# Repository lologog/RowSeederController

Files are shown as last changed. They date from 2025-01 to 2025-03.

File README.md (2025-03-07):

# DC Motor Controller for Row Seeder

## Project Description
This project focuses on the design and development of a modular DC motor controller system for a row seeder.
The system ensures precise control over seed dispensing and supports communication with external devices via CAN protocol.

The project consists of a main controller board an an extension board connected via 2.54mm pin sockets:
- **Main Controller Board**: Handles motor control, sensor readings and CAN communication protocol.
- **Extension Board**: Adds high-current switches and extra digital inputs for expanded functionality.

This modular approach allows future modifications for broader compatibility and functionality.

---

## Features
### Main Controller Board:
- **Microcontroller**: STM32L476RGT6 (low power, high-performance Cortex-M4).
- **DC Motor Control**: H-bridge driver with speed and direction regulation using PWM.
- **CAN Communication**: Communication interface enabled by an SN65HVD230 transceiver, operating with a default baud rate of 500 kbits/s.
- **Sensor Inputs**:
  - Analog inputs (12V) for angle sensors.
  - Encoder inputs (5V and 12V) for speed control.

### Extension Board:
- **Digital Input Expansion**: Additional pins for external sensors or signals.
- **High-current Switches**: Reliable control of external loads through robust switches.
- **Modular Connectivity**: Connects seamlessly to the main board via pin sockets.

---

## PCB Renderings
- **Main Controller Board**:
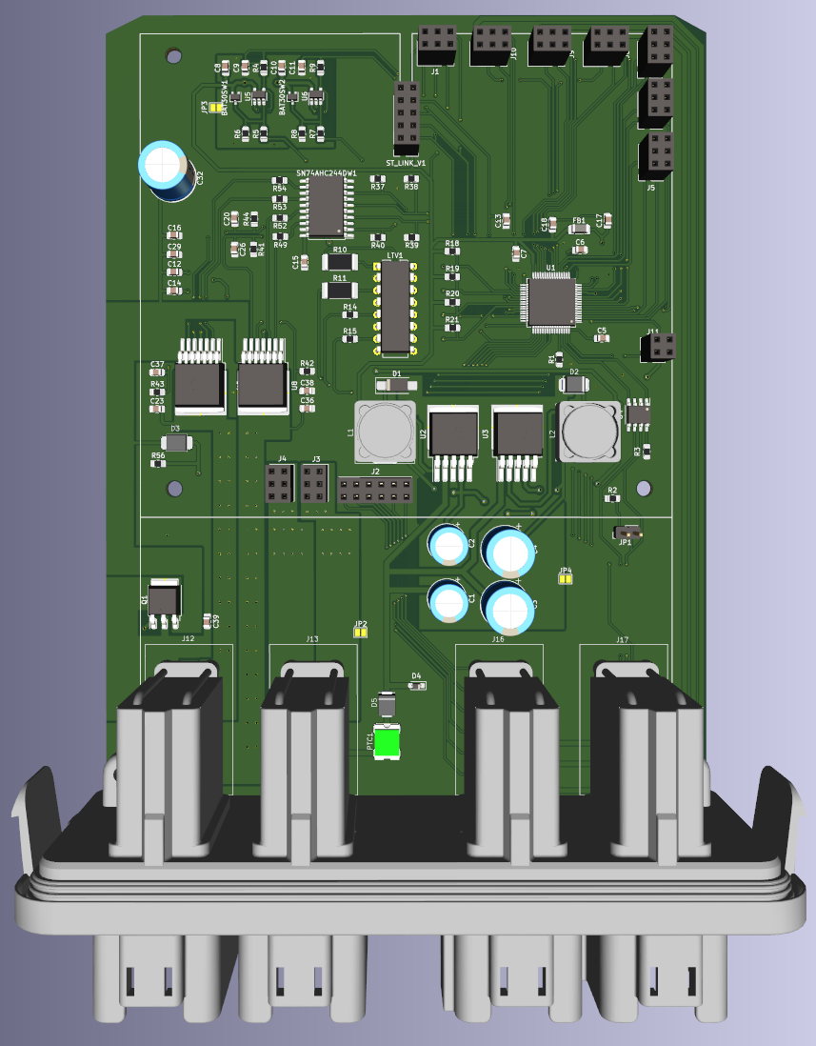
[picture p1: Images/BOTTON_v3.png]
  

- **Extension Board**:
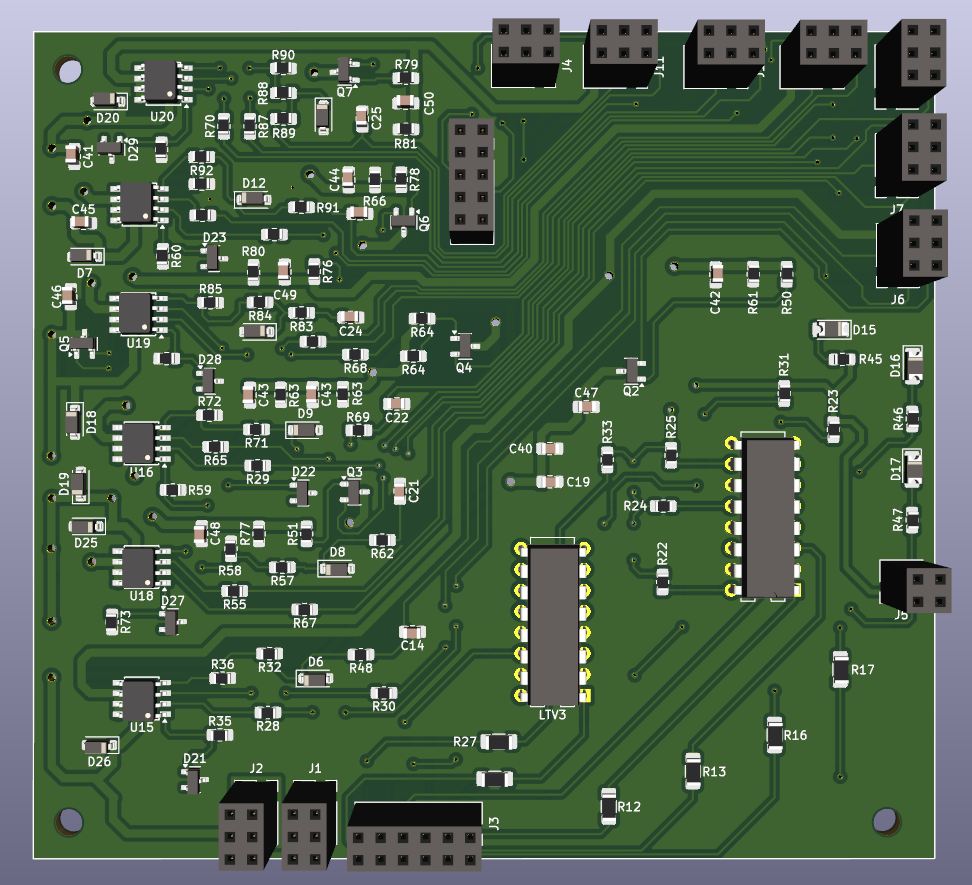
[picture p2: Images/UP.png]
  
  
  *Extension PCB made by my friend :)*

---

## **Real-World Implementation**
Below are images of the actual hardware implementation:

- **Fully assembled main controller**:
    

- **Main controller connected with extension board**:
    

- **Whole controller packed in a cover with 4 connectors**:
    

---

## Results
- **PWM Motor Control**: Verified precise speed and direction control for the DC motor.
- **Sensor Readings**: Successfully processed analog inputs and encoders.
- **PID Algorithm**: Achieved stable motor speed with minimal overshoot and fast response.
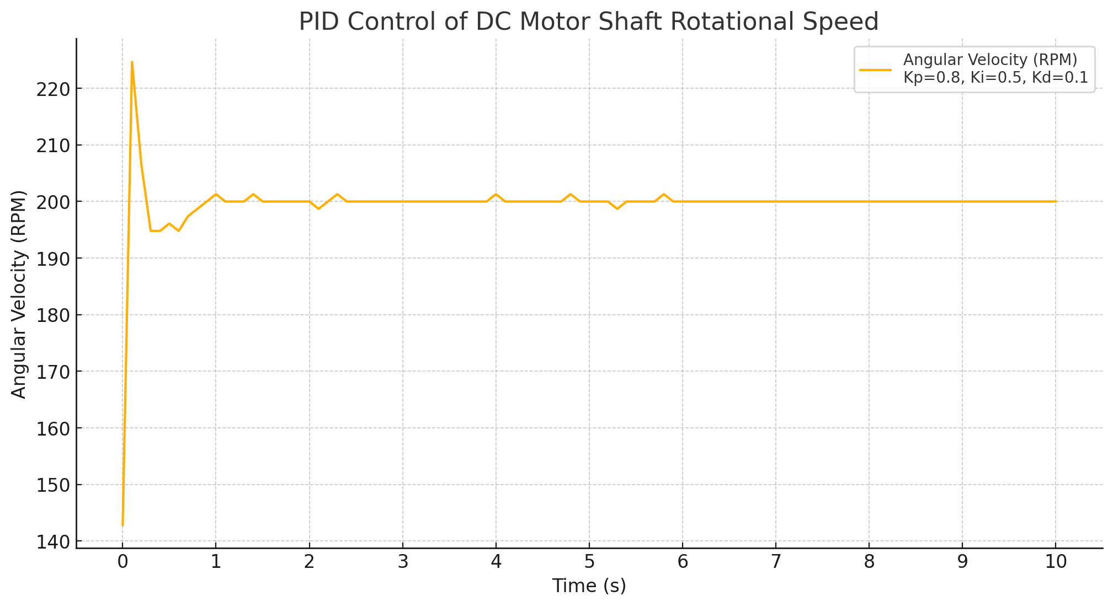
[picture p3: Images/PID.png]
  
  *Example motor angular velocity step response (fs = 10Hz)*
- **CAN Communication**: Reliable message transmission with external systems.
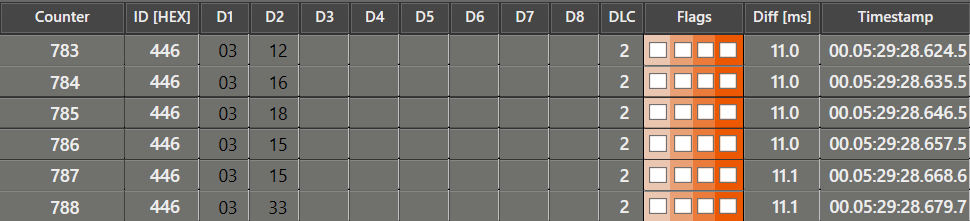
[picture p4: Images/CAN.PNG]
  
  *Sending analog reading of distance sensor via CAN bus*
  
---

## CAN Identifiers Documentation

The following table includes example CAN IDs and their corresponding actions. These IDs are meant as examples and should be adjusted to fit the needs of the target hardware and system.

| ID | Function | Parameters | Message Type | Notes |
|---|---|---|---|---|
| 0x01 | Ping | None | Response | Sends a "ping" response |
| 0x02 | Turn LED ON | None | Request | Turns on the LED |
| 0x03 | Turn LED OFF | None | Request | Turns off the LED |
| 0x04 | Toggle LED state | None | Request | Toggles the LED state |
| 0x05 | Read distance sensor 1  | ADC channel | Request | Reads analog measurement from channel 6 |
| 0x06 | Read distance sensor 2  | ADC channel | Request | Reads analog measurement from channel 7 |
| 0x07 | Turn on/off switch 1 | 1 (ON), other (OFF) | Request | Controls power switch 1 |
| 0x08 | Turn on/off switch 2 | 1 (ON), other (OFF) | Request | Controls power switch 2 |
| 0x09 | Turn on/off switch 3 | 1 (ON), other (OFF) | Request | Controls power switch 3 |
| 0x10 | Turn on/off switch 4 | 1 (ON), other (OFF) | Request | Controls power switch 4 |
| 0x11 | Turn on/off switch 5 | 1 (ON), other (OFF) | Request | Controls power switch 5 |
| 0x12 | Turn on/off switch 6 | 1 (ON), other (OFF) | Request | Controls power switch 6 |
| 0x13 | Motor PID control | RPM, direction | Request | PID control for motor speed |
| 0x14 | Stop motor | None | Request | Stops the motor |
| 0x15 | Motor percent control | Percent, direction | Request | Controls motor using percentage duty cycle|

---

## Potential Improvements
- Support for a broader range of motors and sensors.
- Add more communication protocols and better diagnostic.
- Motor measurement for better motor control.
- Enhanced firmware for fault detection and recovery.
- Improved PID regulation using extrapolation between samples and implementation of angular speed control through current measurement.

## Author
- **Name**: Krzysztof Tomicki
- **Contact**: tomicki.krzysztof.pv@gmail.com

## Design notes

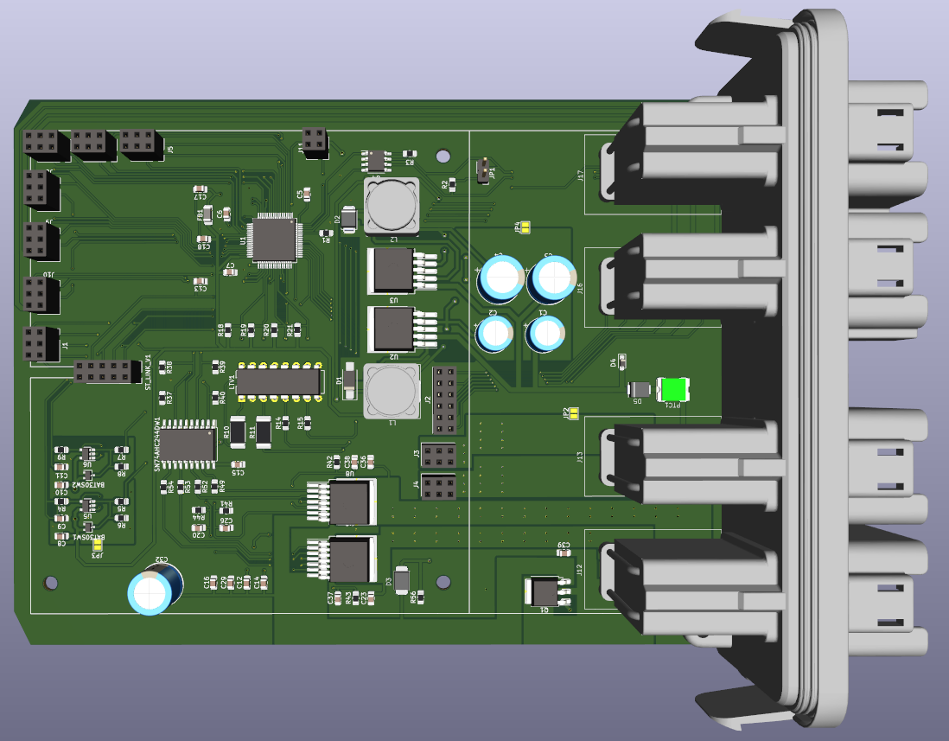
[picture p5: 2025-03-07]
Images/BOTTON_v2.png

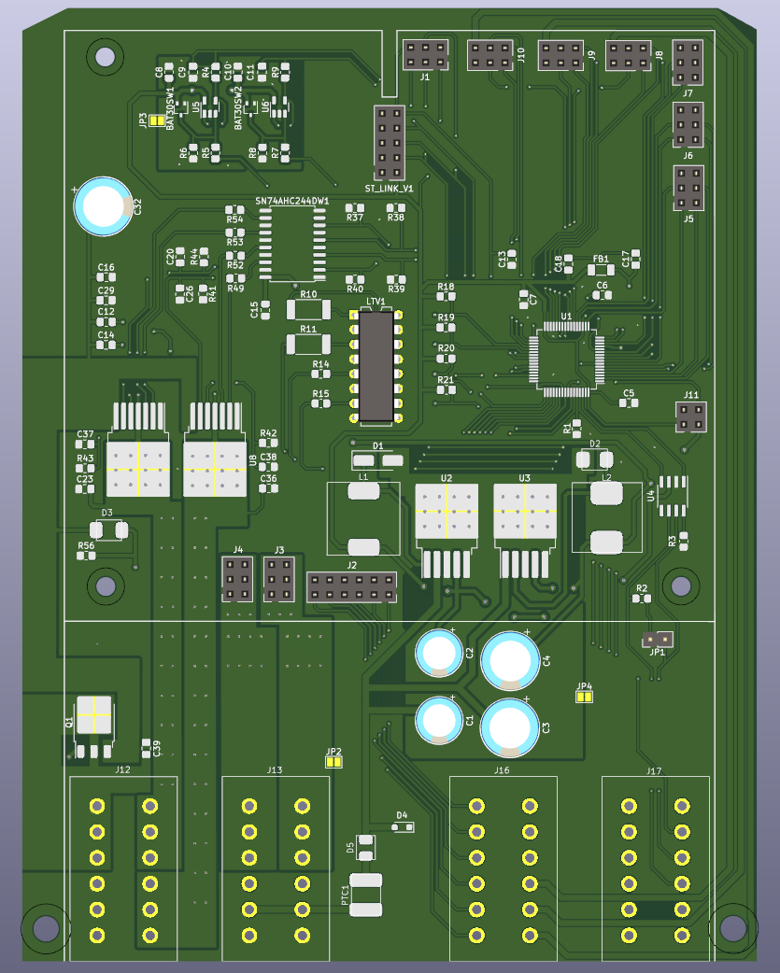
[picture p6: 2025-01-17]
Images/BOTTOM.png

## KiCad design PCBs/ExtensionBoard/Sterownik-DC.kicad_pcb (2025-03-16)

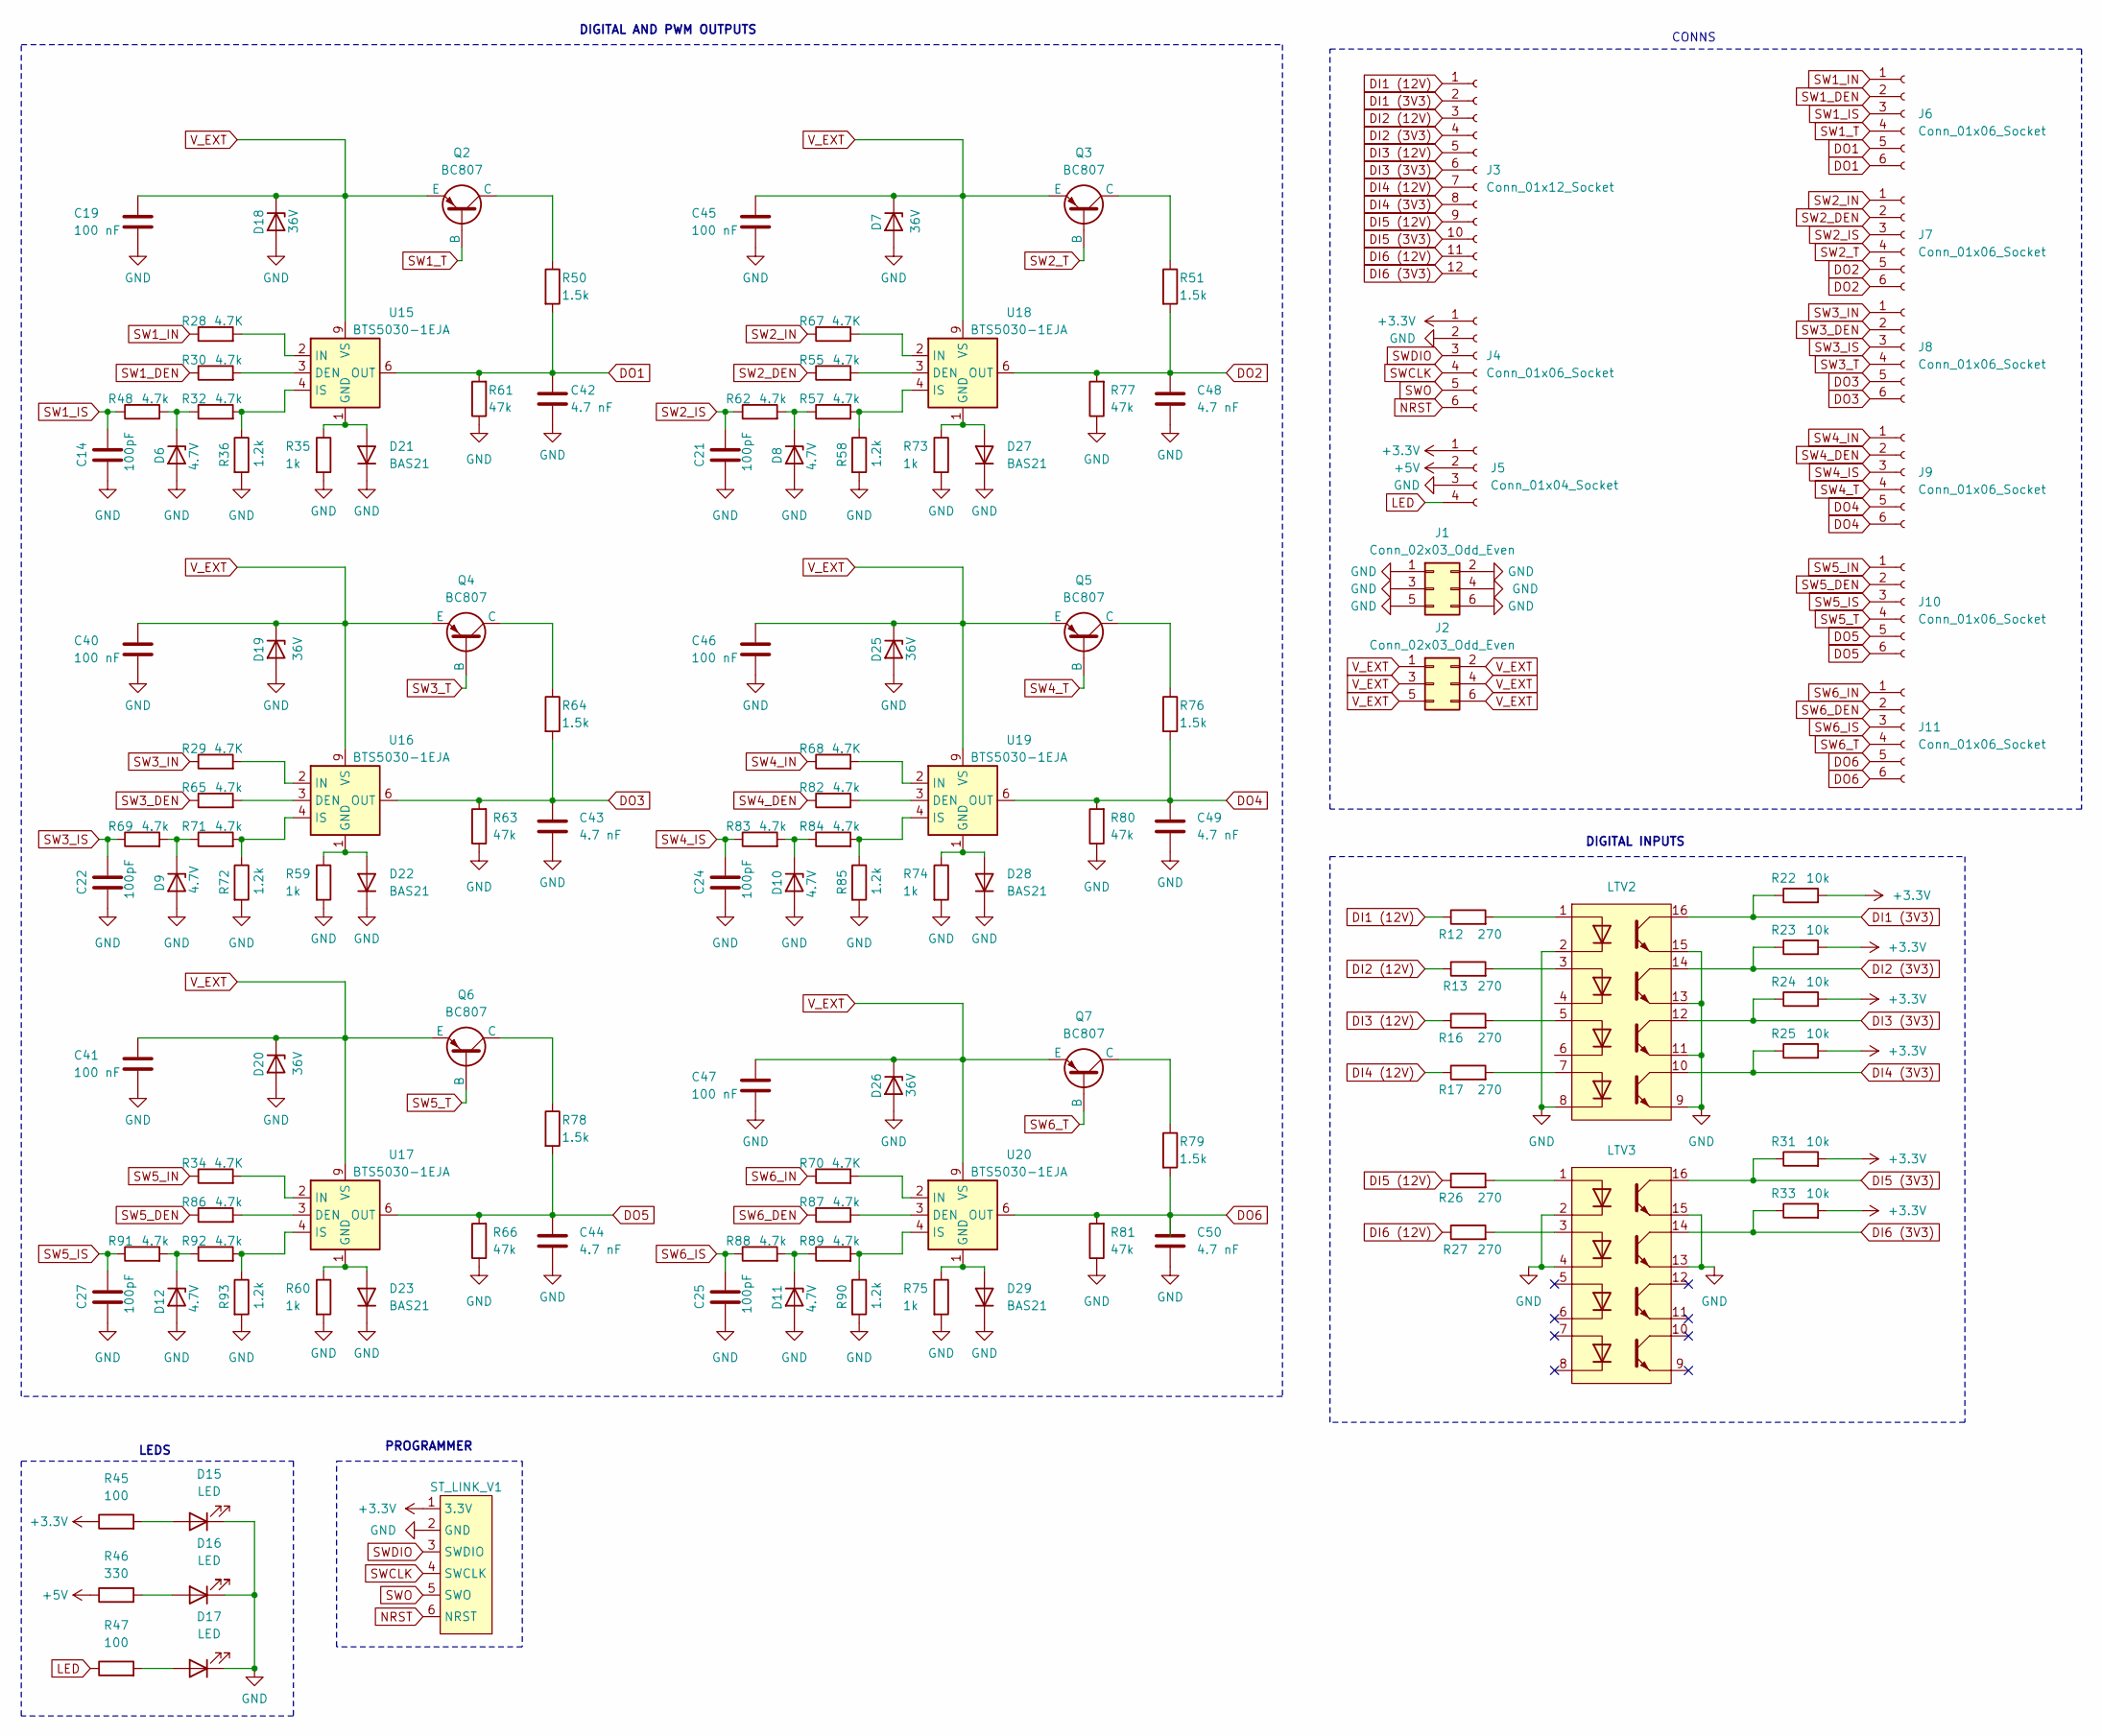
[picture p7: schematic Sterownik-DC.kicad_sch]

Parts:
C14, C21, C22, C24, C25, C27: 100pF; C_0805_2012Metric_Pad1.18x1.45mm_HandSolder
C19, C40, C41, C45, C46, C47: 100 nF; C_0805_2012Metric_Pad1.18x1.45mm_HandSolder
C42, C43, C44, C48, C49, C50: 4.7 nF; C_0805_2012Metric_Pad1.18x1.45mm_HandSolder
D6, D8, D9, D10, D11, D12: 4.7V; D_SOD-123
D7, D18, D19, D20, D25, D26: 36V; D_SOD-123
D15, D16, D17: LED; D_1206_3216Metric_Pad1.42x1.75mm_HandSolder
D21, D22, D23, D27, D28, D29: BAS21; SOT-23
J1, J2: Conn_02x03_Odd_Even; PinSocket_2x03_P2.54mm_Vertical
J3: Conn_01x12_Socket; PinSocket_2x06_P2.54mm_Vertical
J4, J6, J7, J8, J9, J10, J11: Conn_01x06_Socket; PinSocket_2x03_P2.54mm_Vertical
J5: Conn_01x04_Socket; PinSocket_2x02_P2.54mm_Vertical
LTV2, LTV3: DIP-16_W7.62mm
Q2, Q3, Q4, Q5, Q6, Q7: BC807; SOT-23-3
R12, R13, R16, R17, R26, R27: 270; R_1206_3216Metric_Pad1.30x1.75mm_HandSolder
R22, R23, R24, R25, R31, R33: 10k; R_0805_2012Metric_Pad1.20x1.40mm_HandSolder
R28, R29, R34, R67, R68, R70: 4.7K; R_0805_2012Metric_Pad1.20x1.40mm_HandSolder
R30, R32, R48, R55, R57, R62, R65, R69, R71, R82, R83, R84, R86, R87, R88, R89, R91, R92: 4.7k; R_0805_2012Metric_Pad1.20x1.40mm_HandSolder
R35, R59, R60, R73, R74, R75: 1k; R_0805_2012Metric_Pad1.20x1.40mm_HandSolder
R36, R58, R72, R85, R90, R93: 1.2k; R_0805_2012Metric_Pad1.20x1.40mm_HandSolder
R45, R47: 100; R_0805_2012Metric_Pad1.20x1.40mm_HandSolder
R46: 330; R_0805_2012Metric_Pad1.20x1.40mm_HandSolder
R50, R51, R64, R76, R78, R79: 1.5k; R_0805_2012Metric_Pad1.20x1.40mm_HandSolder
R61, R63, R66, R77, R80, R81: 47k; R_0805_2012Metric_Pad1.20x1.40mm_HandSolder
ST_LINK_V1: PinSocket_2x05_P2.54mm_Vertical
U15, U16, U17, U18, U19, U20: BTS5030-1EJA; Infineon_PG-DSO-8-43

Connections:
+3.3V: J4.1, J5.1, R22.2, R23.2, R24.2, R25.2, R31.2, R33.2, R45.1, ST_LINK_V1.1 (3.3V)
+5V: J5.2, R46.1
DI1 (3V3): J3.2, LTV2.16, R22.1
DI1 (12V): J3.1, R12.1
DI2 (3V3): J3.4, LTV2.14, R23.1
DI2 (12V): J3.3, R13.1
DI3 (3V3): J3.6, LTV2.12, R24.1
DI3 (12V): J3.5, R16.1
DI4 (3V3): J3.8, LTV2.10, R25.1
DI4 (12V): J3.7, R17.1
DI5 (3V3): J3.10, LTV3.16, R31.1
DI5 (12V): J3.9, R26.1
DI6 (3V3): J3.12, LTV3.14, R33.1
DI6 (12V): J3.11, R27.1
DO1: C42.1, J6.5, J6.6, R50.2, R61.2, U15.6 (OUT), U15.7 (OUT), U15.8 (OUT)
DO2: C48.1, J7.5, J7.6, R51.2, R77.2, U18.6 (OUT), U18.7 (OUT), U18.8 (OUT)
DO3: C43.1, J8.5, J8.6, R63.2, R64.2, U16.6 (OUT), U16.7 (OUT), U16.8 (OUT); also elsewhere on the board
DO4: C49.1, J9.5, J9.6, R76.2, R80.2, U19.6 (OUT), U19.7 (OUT), U19.8 (OUT)
DO5: C44.1, J10.5, J10.6, R66.2, R78.2, U17.6 (OUT), U17.7 (OUT), U17.8 (OUT)
DO6: C50.1, J11.5, J11.6, R79.2, R81.2, U20.6 (OUT), U20.7 (OUT), U20.8 (OUT)
GND: C14.1, C19.2, C21.1, C22.1, C24.1, C25.1, C27.1, C40.2, C41.2, C42.2, C43.2, C44.2, C45.2, C46.2, C47.2, C48.2, C49.2, C50.2, D6.2 (A), D7.2 (A), D8.2 (A), D9.2 (A), D10.2 (A), D12.2 (A), D15.1 (K), D16.1 (K), D17.1 (K), D18.2 (A), D19.2 (A), D20.2 (A), D21.3 (K), D22.3 (K), D23.3 (K), D25.2 (A), D26.2 (A), D27.3 (K), D28.3 (K), D29.3 (K), J1.1, J1.2, J1.3, J1.4, J1.5, J1.6, J4.2, J5.3, LTV2.2, LTV2.8, LTV2.9, LTV2.11, LTV2.13, LTV2.15, LTV3.2, LTV3.4, LTV3.13, LTV3.15, R35.2, R36.2, R58.2, R59.2, R60.2, R61.1, R63.1, R66.1, R72.2, R73.2, R74.2, R75.2, R77.1, R80.1, R81.1, R85.2, R90.2, R93.2, ST_LINK_V1.2 (GND); also elsewhere on the board
LED: J5.4, R47.1
NRST: J4.6, ST_LINK_V1.6 (NRST)
unnamed: D6.1 (K), R32.1, R48.2
unnamed: D8.1 (K), R57.1, R62.2
unnamed: D9.1 (K), R69.2, R71.1
unnamed: D10.1 (K), R83.2, R84.1
unnamed 27: D11.1 (K), R88.2, R89.1; also elsewhere on the board
unnamed: D12.1 (K), R91.2, R92.1
unnamed: D15.2 (A), R45.2
unnamed: D16.2 (A), R46.2
unnamed: D17.2 (A), R47.2
unnamed: D21.1 (A), R35.1, U15.1 (GND)
unnamed: D22.1 (A), R59.1, U16.1 (GND)
unnamed: D23.1 (A), R60.1, U17.1 (GND)
unnamed: D27.1 (A), R73.1, U18.1 (GND)
unnamed: D28.1 (A), R74.1, U19.1 (GND)
unnamed: D29.1 (A), R75.1, U20.1 (GND)
unnamed: LTV2.1, R12.2
unnamed: LTV2.3, R13.2
unnamed: LTV2.5, R16.2
unnamed: LTV2.7, R17.2
unnamed: LTV3.1, R26.2
unnamed: LTV3.3, R27.2
unnamed: Q2.1 (C), R50.1
unnamed: Q3.1 (C), R51.1
unnamed 46: Q4.1 (C), R64.1; also elsewhere on the board
unnamed: Q5.1 (C), R76.1
unnamed: Q6.1 (C), R78.1
unnamed: Q7.1 (C), R79.1
unnamed: R30.2, U15.3 (DEN)
unnamed: R28.2, U15.2 (IN)
unnamed: R32.2, R36.1, U15.4 (IS)
unnamed: R65.2, U16.3 (DEN)
unnamed: R29.2, U16.2 (IN)
unnamed: R71.2, R72.1, U16.4 (IS)
unnamed: R86.2, U17.3 (DEN)
unnamed: R34.2, U17.2 (IN)
unnamed: R92.2, R93.1, U17.4 (IS)
unnamed: R55.2, U18.3 (DEN)
unnamed: R67.2, U18.2 (IN)
unnamed: R57.2, R58.1, U18.4 (IS)
unnamed: R82.2, U19.3 (DEN)
unnamed: R68.2, U19.2 (IN)
unnamed: R84.2, R85.1, U19.4 (IS)
unnamed: R87.2, U20.3 (DEN)
unnamed: R70.2, U20.2 (IN)
unnamed: R89.2, R90.1, U20.4 (IS)
SW1_DEN: J6.2, R30.1
SW1_IN: J6.1, R28.1
SW1_IS: C14.2, J6.3, R48.1
SW1_T: J6.4, Q2.2 (B)
SW2_DEN: J7.2, R55.1
SW2_IN: J7.1, R67.1
SW2_IS: C21.2, J7.3, R62.1
SW2_T: J7.4, Q3.2 (B)
SW3_DEN: J8.2, R65.1
SW3_IN: J8.1, R29.1
SW3_IS: C22.2, J8.3, R69.1
SW3_T: J8.4, Q4.2 (B)
SW4_DEN: J9.2, R82.1
SW4_IN: J9.1, R68.1
SW4_IS: C24.2, J9.3, R83.1
SW4_T: J9.4, Q5.2 (B)
SW5_DEN: J10.2, R86.1
SW5_IN: J10.1, R34.1
SW5_IS: C27.2, J10.3, R91.1
SW5_T: J10.4, Q6.2 (B)
SW6_DEN: J11.2, R87.1
SW6_IN: J11.1, R70.1
SW6_IS: C25.2, J11.3, R88.1
SW6_T: J11.4, Q7.2 (B)
SWCLK: J4.4, ST_LINK_V1.4 (SWCLK)
SWDIO: J4.3, ST_LINK_V1.3 (SWDIO)
SWO: J4.5, ST_LINK_V1.5 (SWO)
V_EXT: C19.1, C40.1, C41.1, C45.1, C46.1, C47.1, D7.1 (K), D18.1 (K), D19.1 (K), D20.1 (K), D25.1 (K), D26.1 (K), J2.1, J2.2, J2.3, J2.4, J2.5, J2.6, Q2.3 (E), Q3.3 (E), Q4.3 (E), Q5.3 (E), Q6.3 (E), Q7.3 (E), U15.9 (VS), U16.9 (VS), U17.9 (VS), U18.9 (VS), U19.9 (VS), U20.9 (VS)

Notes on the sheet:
CONNS
DIGITAL INPUTS
DIGITAL AND PWM OUTPUTS
LEDS
PROGRAMMER

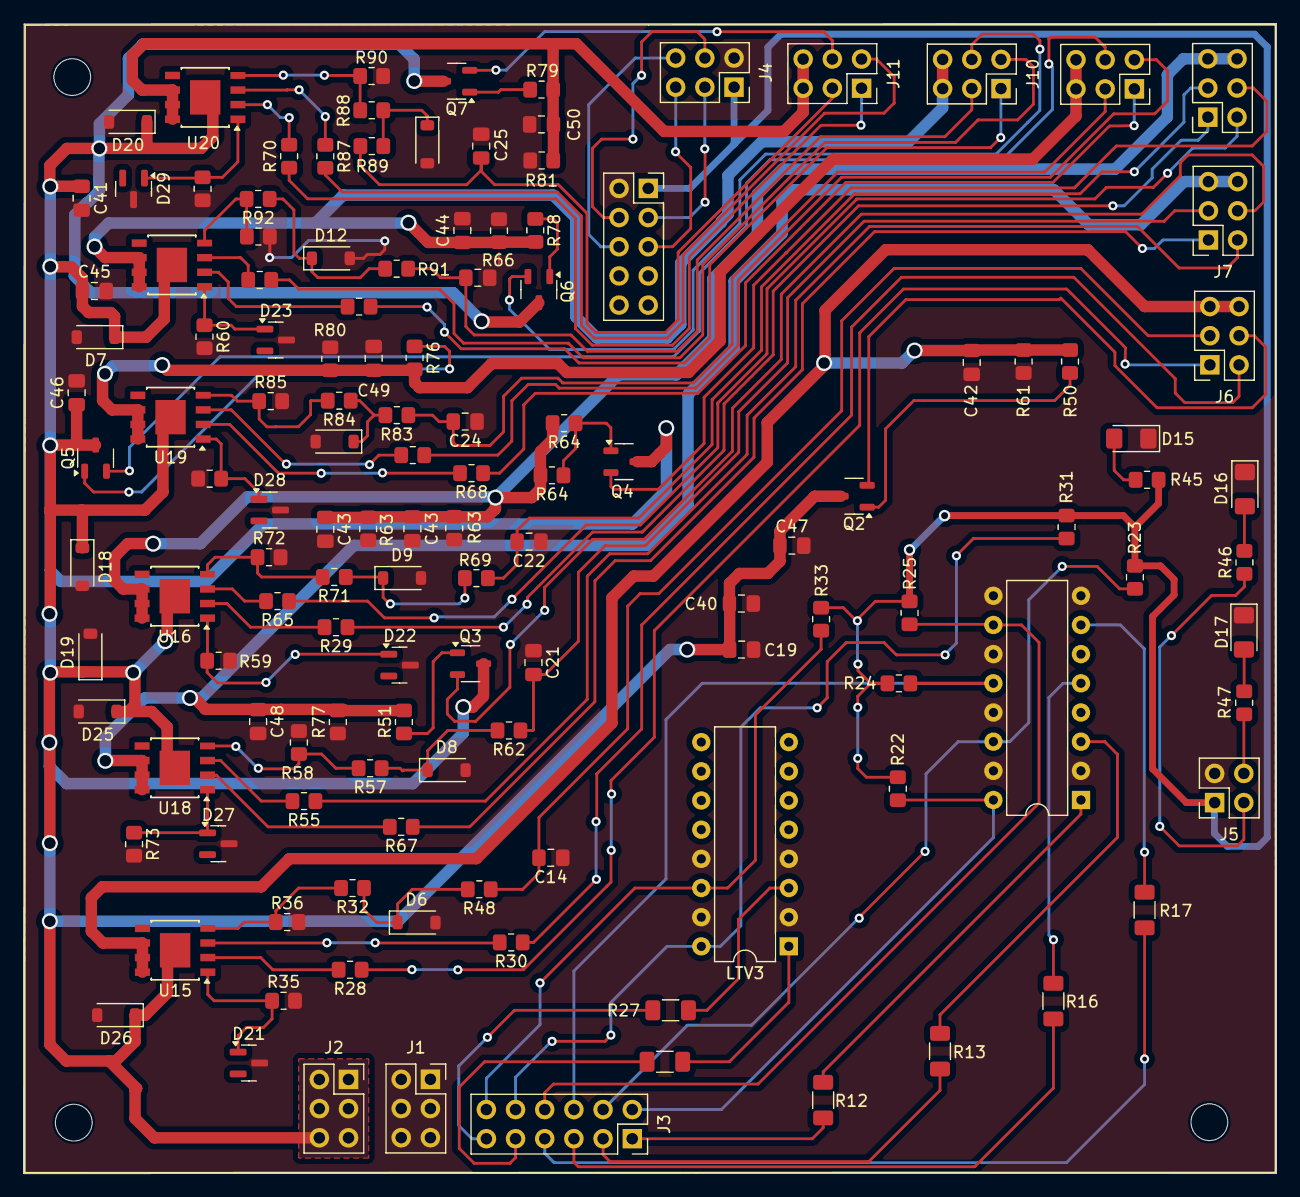
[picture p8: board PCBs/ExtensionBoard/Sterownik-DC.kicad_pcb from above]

Board: 2 copper layers, 109.1 x 100.1 mm, 131 parts (0 on the bottom side), 96 nets.

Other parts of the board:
C25#2: 4.7V; D_SOD-123
C43#2: 4.7 nF; C_0805_2012Metric_Pad1.18x1.45mm_HandSolder
R63#2: 47k; R_0805_2012Metric_Pad1.20x1.40mm_HandSolder
R64#2: 1.5k; R_0805_2012Metric_Pad1.20x1.40mm_HandSolder

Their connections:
DO3: C43#2.1, R63#2.2, R64#2.2; also elsewhere on the board
GND: C25#2.2 (A), C43#2.2, R63#2.1; also elsewhere on the board
unnamed 27: C25#2.1 (K); also elsewhere on the board
unnamed 46: R64#2.1; also elsewhere on the board

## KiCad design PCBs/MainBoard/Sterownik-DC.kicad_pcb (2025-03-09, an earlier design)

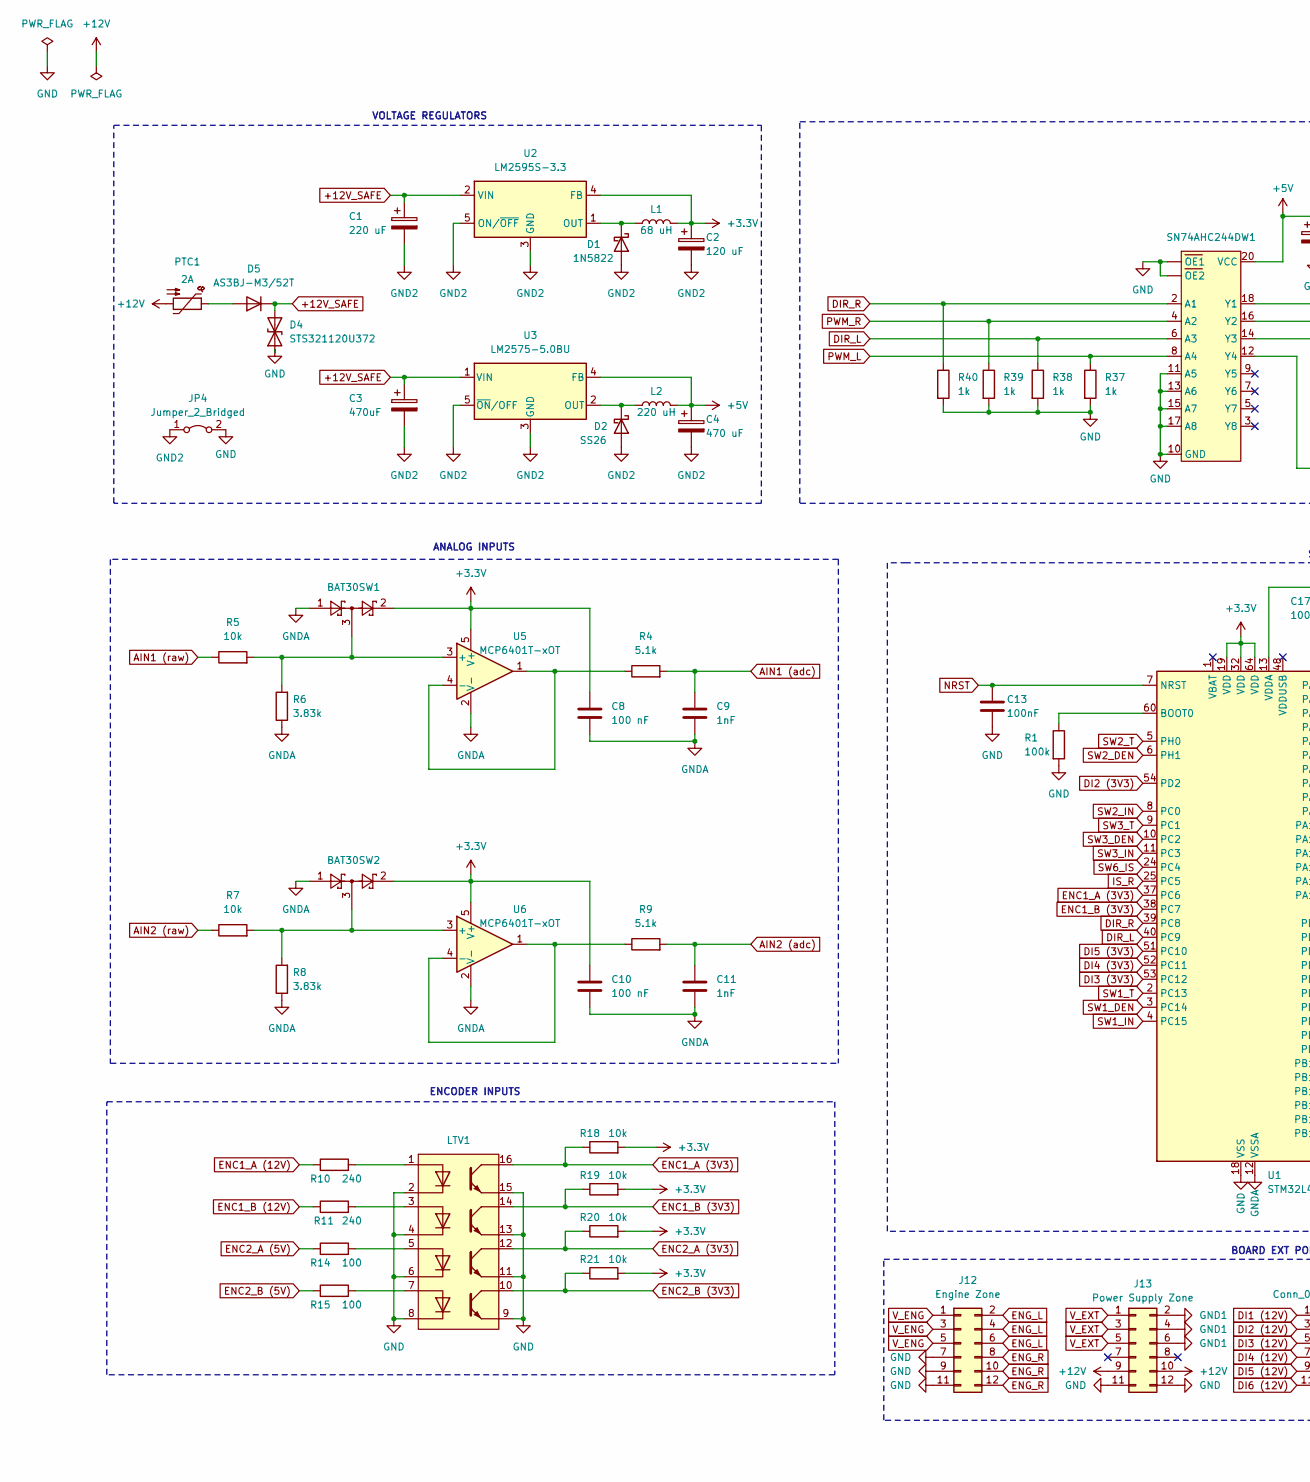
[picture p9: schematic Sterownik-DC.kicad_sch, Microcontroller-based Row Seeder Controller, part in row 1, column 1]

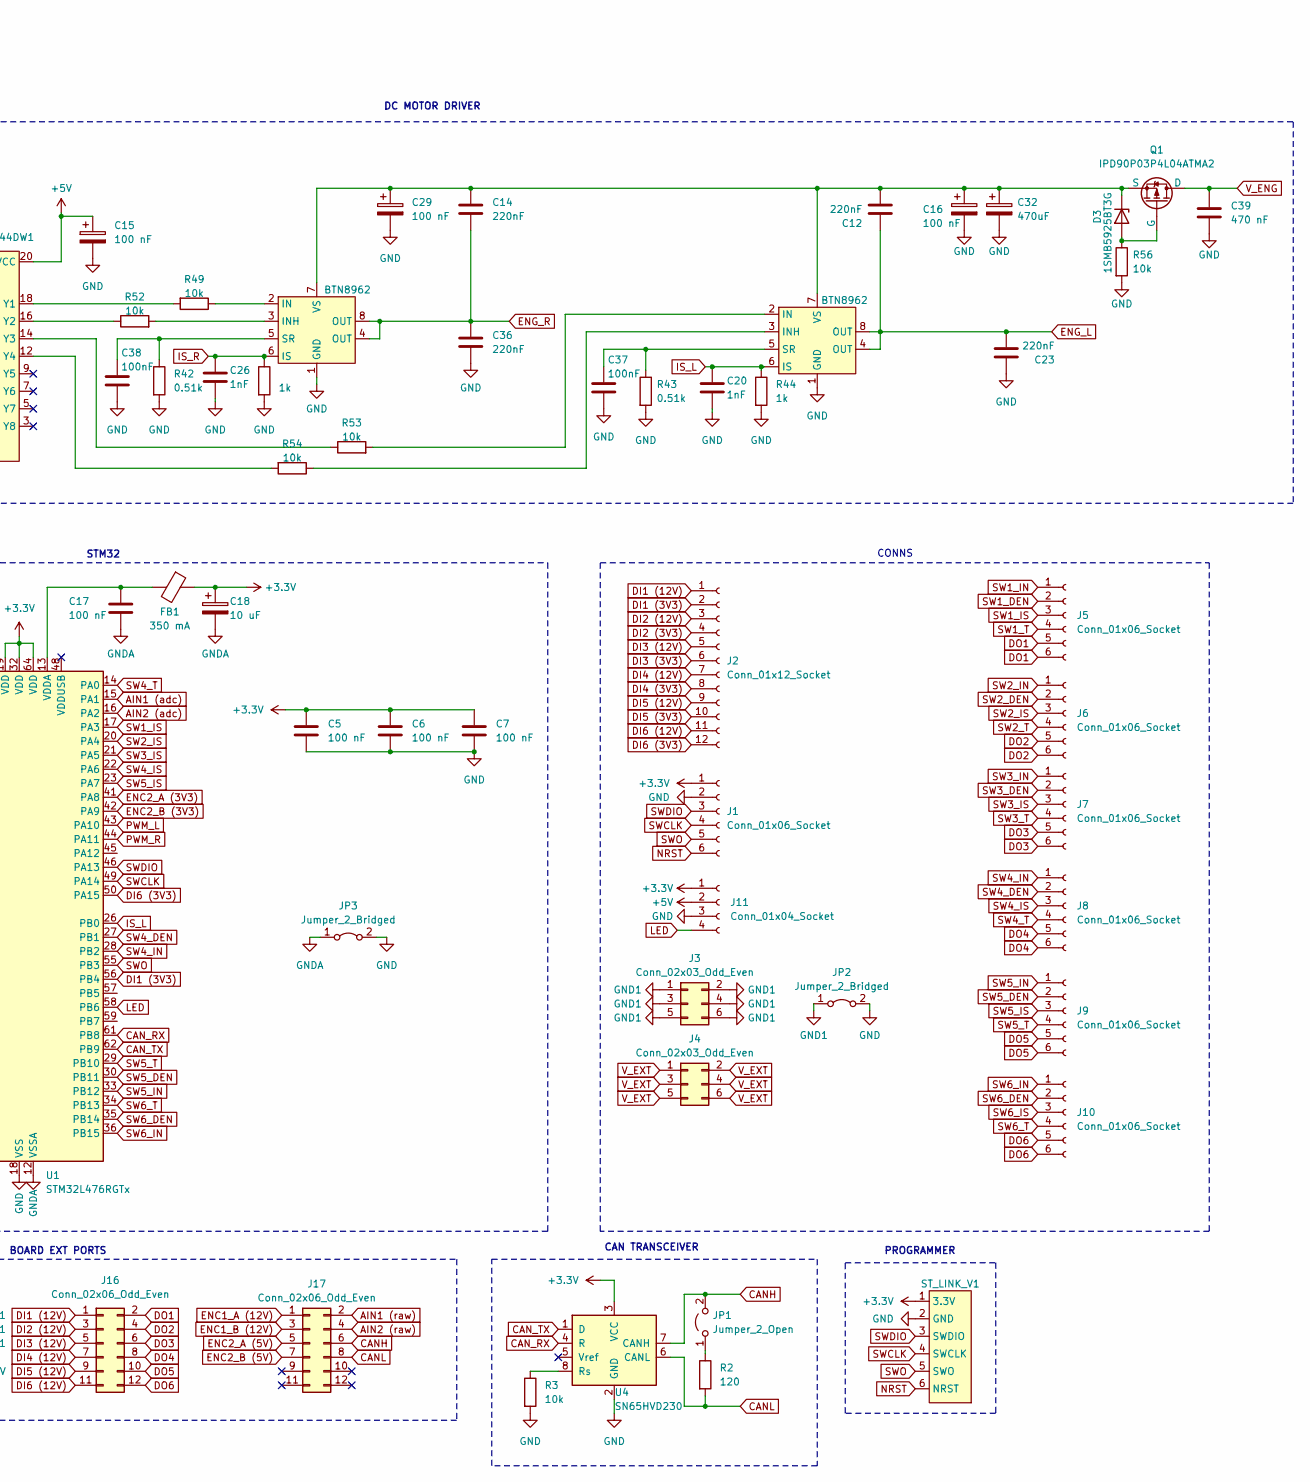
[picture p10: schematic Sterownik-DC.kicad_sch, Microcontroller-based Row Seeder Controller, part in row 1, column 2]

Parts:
BAT30SW1, BAT30SW2: SOT-323_SC-70
C1: 220 uF; CP_Radial_D8.0mm_P3.50mm
C2: 120 uF; CP_Radial_D8.0mm_P3.50mm
C3, C32: 470uF; CP_Radial_D10.0mm_P5.00mm
C4: 470 uF; CP_Radial_D10.0mm_P5.00mm
C5, C6, C7, C8, C10, C15, C16, C17, C29: 100 nF; C_0805_2012Metric_Pad1.18x1.45mm_HandSolder
C9, C11, C20, C26: 1nF; C_0805_2012Metric_Pad1.18x1.45mm_HandSolder
C12, C14, C23, C36: 220nF; C_0805_2012Metric_Pad1.18x1.45mm_HandSolder
C13, C37, C38: 100nF; C_0805_2012Metric_Pad1.18x1.45mm_HandSolder
C18: 10 uF; C_0805_2012Metric_Pad1.18x1.45mm_HandSolder
C39: 470 nF; C_0805_2012Metric_Pad1.18x1.45mm_HandSolder
D1: 1N5822; D_SMA_Handsoldering
D2: SS26; Zener_diode_DO-214AA
D3: 1SMB5925BT3G; 1SMB5913BT3
D4: STS321120U372; D_SOD-323_HandSoldering
D5: AS3BJ-M3/52T; AS3BJ-M3-52T
FB1: 350 mA; L_1206_3216Metric_Pad1.22x1.90mm_HandSolder
J1, J5, J6, J7, J8, J9, J10: Conn_01x06_Socket; PinSocket_2x03_P2.54mm_Vertical
J2: Conn_01x12_Socket; PinSocket_2x06_P2.54mm_Vertical
J3, J4: Conn_02x03_Odd_Even; PinSocket_2x03_P2.54mm_Vertical
J11: Conn_01x04_Socket; PinSocket_2x02_P2.54mm_Vertical
J12: Engine Zone; BIG_CONN
J13: Power Supply Zone; BIG_CONN
J16, J17: Conn_02x06_Odd_Even; BIG_CONN
JP1: Jumper_2_Open; PinHeader_1x02_P2.54mm_Vertical
JP2, JP3, JP4: Jumper_2_Bridged; SolderJumper-2_P1.3mm_Bridged2Bar_Pad1.0x1.5mm
L1: 68 uH; SRR1280
L2: 220 uH; MSS1246T
LTV1: DIP-16_W7.62mm
PTC1: 2A; 0ZCF Series
Q1: IPD90P03P4L04ATMA2; TO-252-3_TabPin2
R1: 100k; R_0805_2012Metric_Pad1.20x1.40mm_HandSolder
R2: 120; R_0805_2012Metric_Pad1.20x1.40mm_HandSolder
R3, R5, R7, R18, R19, R20, R21, R49, R52, R53, R54, R56: 10k; R_0805_2012Metric_Pad1.20x1.40mm_HandSolder
R4, R9: 5.1k; R_0805_2012Metric_Pad1.20x1.40mm_HandSolder
R6, R8: 3.83k; R_0805_2012Metric_Pad1.20x1.40mm_HandSolder
R10, R11: 240; R_2512_6332Metric_Pad1.40x3.35mm_HandSolder
R14, R15: 100; R_0805_2012Metric_Pad1.20x1.40mm_HandSolder
R37, R38, R39, R40, R41, R44: 1k; R_0805_2012Metric_Pad1.20x1.40mm_HandSolder
R42, R43: 0.51k; R_0805_2012Metric_Pad1.20x1.40mm_HandSolder
SN74AHC244DW1: SOIC-20W_7.5x12.8mm_P1.27mm
ST_LINK_V1: PinSocket_2x05_P2.54mm_Vertical
U1: STM32L476RGTx; LQFP-64_10x10mm_P0.5mm
U2: LM2595S-3.3; TO-263-5_TabPin3
U3: LM2575-5.0BU; TO-263-5_TabPin3
U4: SN65HVD230; SOIC-8_3.9x4.9mm_P1.27mm
U5, U6: MCP6401T-xOT; SOT-23-5
U8, U9: BTN8962; TO-263-7_TabPin8

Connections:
+3.3V: BAT30SW1.2, BAT30SW2.2, C2.1, C5.1, C6.1, C7.1, C8.1, C10.1, C18.1, FB1.1, J1.1, J11.1, L1.2, R18.2, R19.2, R20.2, R21.2, ST_LINK_V1.1 (3.3V), U1.19 (VDD), U1.32 (VDD), U1.64 (VDD), U2.4 (FB), U4.3 (VCC), U5.5 (V+), U6.5 (V+)
+5V: C4.1, C15.1, J11.2, L2.2, SN74AHC244DW1.20 (VCC), U3.4 (FB)
+12V: J13.9, J13.10, PTC1.2
+12V_SAFE: C1.1, C3.1, D4.2 (A2), D5.1 (K), U2.2 (VIN), U3.1 (VIN)
AIN1 (adc): C9.1, R4.2, U1.15 (PA1)
AIN1 (raw): J17.2, R5.1
AIN2 (adc): C11.1, R9.2, U1.16 (PA2)
AIN2 (raw): J17.4, R7.1
CANH: J17.6, JP1.2 (B), U4.7 (CANH)
CANL: J17.8, R2.2, U4.6 (CANL)
CAN_RX: U1.61 (PB8), U4.4 (R)
CAN_TX: U1.62 (PB9), U4.1 (D)
DI1 (3V3): J2.2, U1.56 (PB4)
DI1 (12V): J2.1, J16.1
DI2 (3V3): J2.4, U1.54 (PD2)
DI2 (12V): J2.3, J16.3
DI3 (3V3): J2.6, U1.53 (PC12)
DI3 (12V): J2.5, J16.5
DI4 (3V3): J2.8, U1.52 (PC11)
DI4 (12V): J2.7, J16.7
DI5 (3V3): J2.10, U1.51 (PC10)
DI5 (12V): J2.9, J16.9
DI6 (3V3): J2.12, U1.50 (PA15)
DI6 (12V): J2.11, J16.11
DIR_L: R38.1, SN74AHC244DW1.6 (A3), U1.40 (PC9)
DIR_R: R40.1, SN74AHC244DW1.2 (A1), U1.39 (PC8)
DO1: J5.5, J5.6, J16.2
DO2: J6.5, J6.6, J16.4
DO3: J7.5, J7.6, J16.6
DO4: J8.5, J8.6, J16.8
DO5: J9.5, J9.6, J16.10
DO6: J10.5, J10.6, J16.12
ENC1_A (3V3): LTV1.16, R18.1, U1.37 (PC6)
ENC1_A (12V): J17.1, R10.1
ENC1_B (3V3): LTV1.14, R19.1, U1.38 (PC7)
ENC1_B (12V): J17.3, R11.1
ENC2_A (3V3): LTV1.12, R20.1, U1.41 (PA8)
ENC2_A (5V): J17.5, R14.1
ENC2_B (3V3): LTV1.10, R21.1, U1.42 (PA9)
ENC2_B (5V): J17.7, R15.1
ENG_L: C12.1, C23.2, J12.2, J12.4, J12.6, U9.4 (OUT), U9.8 (OUT)
ENG_R: C14.2, C36.1, J12.8, J12.10, J12.12, U8.4 (OUT), U8.8 (OUT)
GND: C5.2, C6.2, C7.2, C13.2, C15.2, C16.2, C20.2, C23.1, C26.2, C29.2, C32.2, C36.2, C37.2, C38.2, C39.2, D4.1 (A1), J1.2, J11.3, J12.7, J12.9, J12.11, J13.11, J13.12, JP2.2 (B), JP3.2 (B), JP4.2 (B), LTV1.2, LTV1.4, LTV1.6, LTV1.8, LTV1.9, LTV1.11, LTV1.13, LTV1.15, R1.2, R3.2, R37.2, R38.2, R39.2, R40.2, R41.2, R42.2, R43.2, R44.2, R56.2, SN74AHC244DW1. (OE1), SN74AHC244DW1.1 (OE1), SN74AHC244DW1.10 (GND), SN74AHC244DW1.11 (A5), SN74AHC244DW1.13 (A6), SN74AHC244DW1.15 (A7), SN74AHC244DW1.17 (A8), SN74AHC244DW1.19 (OE2), ST_LINK_V1.2 (GND), U1.18 (VSS), U1.31 (VSS), U1.47 (VSS), U1.63 (VSS), U4.2 (GND), U8.1 (GND), U9.1 (GND)
GND1: J3.1, J3.2, J3.3, J3.4, J3.5, J3.6, J13.2, J13.4, J13.6, JP2.1 (A)
GND2: C1.2, C2.2, C3.2, C4.2, D1.2 (A), D2.2 (A), JP4.1 (A), U2.3 (GND), U2.5 (ON/~OFF), U3.3 (GND), U3.5 (~ON/OFF)
GNDA: BAT30SW1.1, BAT30SW2.1, C8.2, C9.2, C10.2, C11.2, C17.2, C18.2, JP3.1 (A), R6.1, R8.1, U1.12 (VSSA), U5.2 (V-), U6.2 (V-)
IS_L: C20.1, R44.1, U1.26 (PB0), U9.6 (IS)
IS_R: C26.1, R41.1, U1.25 (PC5), U8.6 (IS)
LED: J11.4, U1.58 (PB6)
NRST: C13.1, J1.6, ST_LINK_V1.6 (NRST), U1.7 (NRST)
unnamed: D1.1 (K), L1.1, U2.1 (OUT)
unnamed: D2.1 (K), L2.1, U3.2 (OUT)
unnamed: D3.2 (A), Q1.1 (G), R56.1
unnamed: C12.2, C14.1, C16.1, C29.1, C32.1, D3.1 (K), Q1.3 (S), U8.7 (VS), U9.7 (VS)
unnamed: D5.2 (A), PTC1.1
unnamed: JP1.1 (A), R2.1
unnamed: LTV1.1, R10.2
unnamed: LTV1.3, R11.2
unnamed: LTV1.5, R14.2
unnamed: LTV1.7, R15.2
unnamed: R49.2, SN74AHC244DW1.18 (Y1)
unnamed: R52.1, SN74AHC244DW1.16 (Y2)
unnamed: R53.1, SN74AHC244DW1.14 (Y3)
unnamed: R54.2, SN74AHC244DW1.12 (Y4)
unnamed: R1.1, U1.60 (BOOT0)
unnamed: C17.1, FB1.2, U1.13 (VDDA)
unnamed: R3.1, U4.8 (Rs)
unnamed: BAT30SW1.3, R5.2, R6.2, U5.3 (+)
unnamed: R4.1, U5.1, U5.4 (-)
unnamed: BAT30SW2.3, R7.2, R8.2, U6.3 (+)
unnamed: R9.1, U6.1, U6.4 (-)
unnamed: R49.1, U8.2 (IN)
unnamed: R52.2, U8.3 (INH)
unnamed: C38.1, R42.1, U8.5 (SR)
unnamed: R53.2, U9.2 (IN)
unnamed: R54.1, U9.3 (INH)
unnamed: C37.1, R43.1, U9.5 (SR)
PWM_L: R37.1, SN74AHC244DW1.8 (A4), U1.43 (PA10)
PWM_R: R39.1, SN74AHC244DW1.4 (A2), U1.44 (PA11)
SW1_DEN: J5.2, U1.3 (PC14)
SW1_IN: J5.1, U1.4 (PC15)
SW1_IS: J5.3, U1.17 (PA3)
SW1_T: J5.4, U1.2 (PC13)
SW2_DEN: J6.2, U1.6 (PH1)
SW2_IN: J6.1, U1.8 (PC0)
SW2_IS: J6.3, U1.20 (PA4)
SW2_T: J6.4, U1.5 (PH0)
SW3_DEN: J7.2, U1.10 (PC2)
SW3_IN: J7.1, U1.11 (PC3)
SW3_IS: J7.3, U1.21 (PA5)
SW3_T: J7.4, U1.9 (PC1)
SW4_DEN: J8.2, U1.27 (PB1)
SW4_IN: J8.1, U1.28 (PB2)
SW4_IS: J8.3, U1.22 (PA6)
SW4_T: J8.4, U1.14 (PA0)
SW5_DEN: J9.2, U1.30 (PB11)
SW5_IN: J9.1, U1.33 (PB12)
SW5_IS: J9.3, U1.23 (PA7)
SW5_T: J9.4, U1.29 (PB10)
SW6_DEN: J10.2, U1.35 (PB14)
SW6_IN: J10.1, U1.36 (PB15)
SW6_IS: J10.3, U1.24 (PC4)
SW6_T: J10.4, U1.34 (PB13)
SWCLK: J1.4, ST_LINK_V1.4 (SWCLK), U1.49 (PA14)
SWDIO: J1.3, ST_LINK_V1.3 (SWDIO), U1.46 (PA13)
SWO: J1.5, ST_LINK_V1.5 (SWO), U1.55 (PB3)
V_ENG: C39.1, J12.1, J12.3, J12.5, Q1.2 (D)
V_EXT: J4.1, J4.2, J4.3, J4.4, J4.5, J4.6, J13.1, J13.3, J13.5

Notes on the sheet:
DC MOTOR DRIVER
CONNS
PROGRAMMER
CAN TRANSCEIVER
ANALOG INPUTS
BOARD EXT PORTS
ENCODER INPUTS
STM32
VOLTAGE REGULATORS

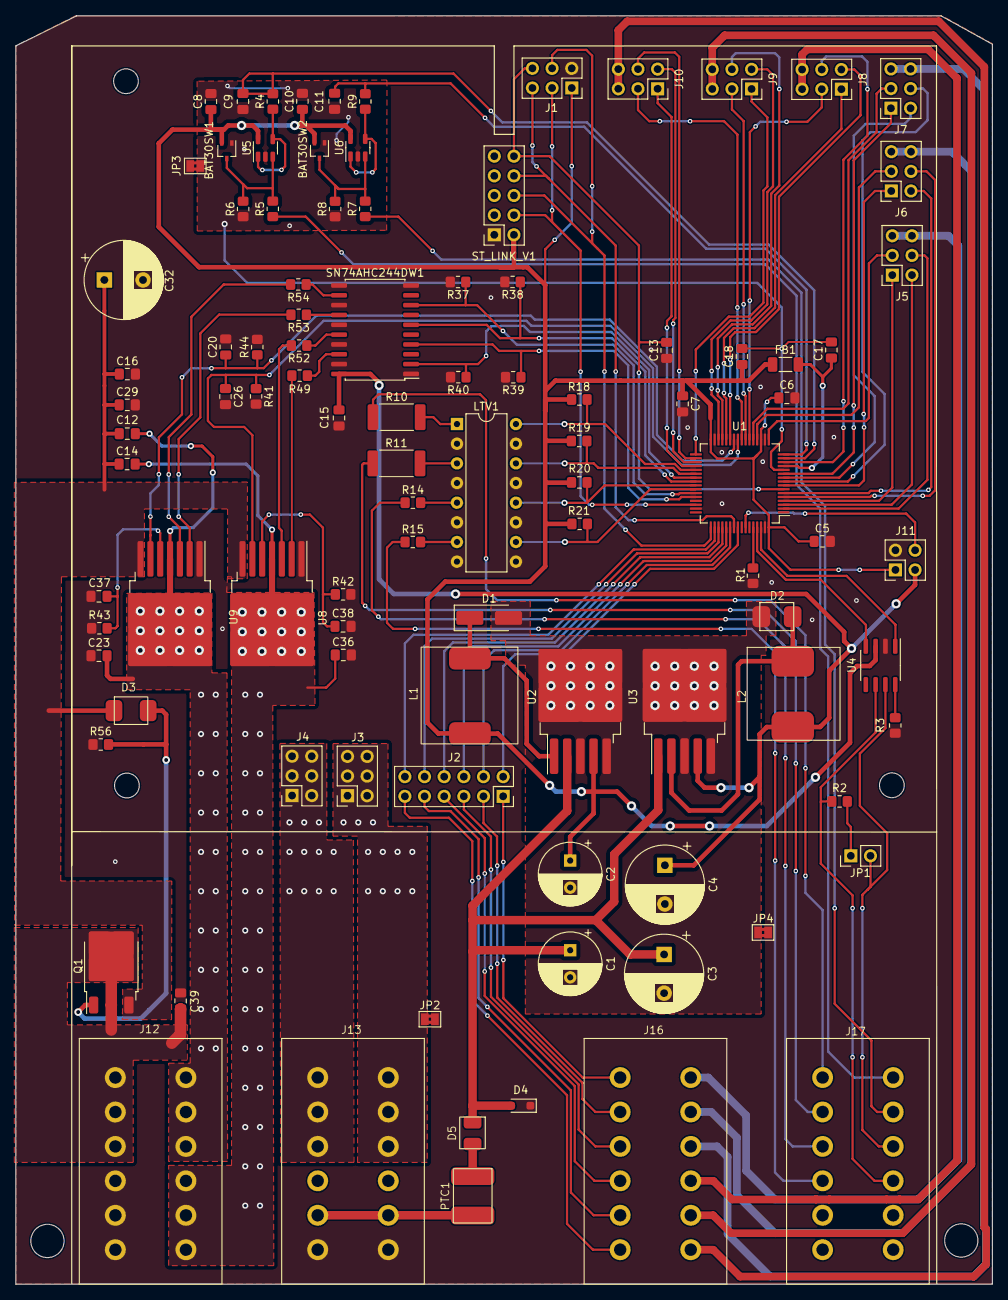
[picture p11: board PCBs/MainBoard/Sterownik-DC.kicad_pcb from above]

Board: 2 copper layers, 126.2 x 163.9 mm, 99 parts (0 on the bottom side), 108 nets.

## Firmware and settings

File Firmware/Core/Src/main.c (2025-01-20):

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
/* Includes ------------------------------------------------------------------*/
#include "main.h"

/* USER CODE BEGIN Includes */
#include "motor.h"
#include "led.h"
#include "encoder.h"
#include "can.h"
#include  "can_logic.h"
/* USER CODE END Includes */

ADC_HandleTypeDef hadc1;

CAN_HandleTypeDef hcan1;

TIM_HandleTypeDef htim1;
TIM_HandleTypeDef htim2;
TIM_HandleTypeDef htim4;
TIM_HandleTypeDef htim8;

void SystemClock_Config(void);
static void MX_GPIO_Init(void);
static void MX_ADC1_Init(void);
static void MX_TIM1_Init(void);
static void MX_TIM4_Init(void);
static void MX_TIM8_Init(void);
static void MX_TIM2_Init(void);
static void MX_CAN1_Init(void);
/* USER CODE BEGIN 0 */
//interrupt if something went through CAN filters and is in FIFO0
void HAL_CAN_RxFifo0MsgPendingCallback(CAN_HandleTypeDef *hcan)
{
    CAN_RxHeaderTypeDef RxHeader;
    uint8_t rxData[8];

    if (HAL_CAN_GetRxMessage(hcan, CAN_RX_FIFO0, &RxHeader, rxData) == HAL_OK)
    {
    	//function with logic
        Process_CAN_Message(RxHeader.StdId, rxData, RxHeader.DLC);
    }
}

uint32_t adc_value[10];
// choosing channel and getting ADC value
uint32_t Read_ADC(ADC_HandleTypeDef *hadc, uint32_t AdcChannel)
{
	// configuration
	ADC_ChannelConfTypeDef sConfig = {0};
	sConfig.Channel = AdcChannel;
	sConfig.Rank = 1;
	sConfig.SamplingTime = ADC_SAMPLETIME_2CYCLE_5;
	if (HAL_ADC_ConfigChannel(hadc, &sConfig) != HAL_OK)
	{
		Error_Handler();
	}

	//read ADC value
	HAL_ADC_Start(hadc);
	if (HAL_ADC_PollForConversion(hadc, 10) == HAL_OK)
	{
		return HAL_ADC_GetValue(hadc);
	}
	else
	{
		Error_Handler();
		return 0;
	}
}

// Toggling state of IN pin of power switches
void PowerSwitchOnOffDiagnostic(uint8_t DeviceNumber, GPIO_PinState PinState)
{
    switch(DeviceNumber)
    {
        case 1:
            HAL_GPIO_WritePin(SW1_IN_GPIO_Port, SW1_IN_Pin, PinState);
            break;
        case 2:
            HAL_GPIO_WritePin(SW2_IN_GPIO_Port, SW2_IN_Pin, PinState);
            break;
        case 3:
            HAL_GPIO_WritePin(SW3_IN_GPIO_Port, SW3_IN_Pin, PinState);
            break;
        case 4:
            HAL_GPIO_WritePin(SW4_IN_GPIO_Port, SW4_IN_Pin, PinState);
            break;
        case 5:
            HAL_GPIO_WritePin(SW5_IN_GPIO_Port, SW5_IN_Pin, PinState);
            break;
        case 6:
            HAL_GPIO_WritePin(SW6_IN_GPIO_Port, SW6_IN_Pin, PinState);
            break;
        default:
            break;
    }
}

uint16_t RPM = 0;
MotorDirection_t direction = MOTOR_LEFT;
uint8_t duty = 0;
uint8_t motor_percent_flag = 0;
/* USER CODE END 0 */

/**
  * @brief  The application entry point.
  * @retval int
  */
int main(void)
{
  /* MCU Configuration--------------------------------------------------------*/

  /* Reset of all peripherals, Initializes the Flash interface and the Systick. */
  HAL_Init();

  /* Configure the system clock */
  SystemClock_Config();

  /* Initialize all configured peripherals */
  MX_GPIO_Init();
  MX_ADC1_Init();
  MX_TIM1_Init();
  MX_TIM4_Init();
  MX_TIM8_Init();
  MX_TIM2_Init();
  MX_CAN1_Init();
  /* USER CODE BEGIN 2 */
  Motor_Init();
  Encoder_Init(ENCODER_5V);
  Encoder_Init(ENCODER_12V);
  CAN_Init(&hcan1);
  CAN_ConfigFilters(&hcan1, 0x000, 0x000); //mask will check all bytes of ID if the mask value is set to 0x7FF
  HAL_TIM_Base_Start_IT(&htim2);
  HAL_ADC_Start(&hadc1);

  //turn off all diagnostic pins of power switches
  for (uint8_t i = 0; i < 6; i++)
  {
	 PowerSwitchOnOffDiagnostic(i, 0);
  }

  /* USER CODE END 2 */

  /* Infinite loop */
  /* USER CODE BEGIN WHILE */
  while (1)
  {
	  //percent motor control possible to enable by CAN
	  if (motor_percent_flag == 1)
	  {
		  Motor_Percent_Control(direction, duty);
	  }
    /* USER CODE END WHILE */

    /* USER CODE BEGIN 3 */
  }
  /* USER CODE END 3 */
}

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
/* USER CODE BEGIN 4 */

/* TIM2 interrupt handler for RPM measurement */
void HAL_TIM_PeriodElapsedCallback(TIM_HandleTypeDef *htim)
{
    if (htim->Instance == TIM2) // Check if the interrupt is from TIM2
    {
        uint32_t desired_RPM = RPM * 1000; // Desired RPM scaled by 1000
        uint32_t current_RPM = Encoder_GetScaledRPM(ENCODER_5V); // Scaled RPM

    	//We need to split 32 bit int into 4x8bit bytes to send via CAN bus
    	uint8_t byte1 = (current_RPM >> 24) & 0xFF; //MSB
    	uint8_t byte2 = (current_RPM >> 16) & 0xFF;
    	uint8_t byte3 = (current_RPM >> 8) & 0xFF;
    	uint8_t byte4 = current_RPM & 0xFF; //LSB

    	CAN_SendMessage(&hcan1, 0x200, (uint8_t[]){byte1, byte2, byte3, byte4}, 4);

    	Motor_PID_Control(direction, desired_RPM, current_RPM);
    }
}
/* USER CODE END 4 */
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


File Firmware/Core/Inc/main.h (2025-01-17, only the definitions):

#define SW1_T_Pin GPIO_PIN_13
#define SW1_T_GPIO_Port GPIOC
#define SW1_DEN_Pin GPIO_PIN_14
#define SW1_DEN_GPIO_Port GPIOC
#define SW1_IN_Pin GPIO_PIN_15
#define SW1_IN_GPIO_Port GPIOC
#define SW2_T_Pin GPIO_PIN_0
#define SW2_T_GPIO_Port GPIOH
#define SW2_DEN_Pin GPIO_PIN_1
#define SW2_DEN_GPIO_Port GPIOH
#define SW2_IN_Pin GPIO_PIN_0
#define SW2_IN_GPIO_Port GPIOC
#define SW3_T_Pin GPIO_PIN_1
#define SW3_T_GPIO_Port GPIOC
#define SW3_DEN_Pin GPIO_PIN_2
#define SW3_DEN_GPIO_Port GPIOC
#define SW3_IN_Pin GPIO_PIN_3
#define SW3_IN_GPIO_Port GPIOC
#define SW4_T_Pin GPIO_PIN_0
#define SW4_T_GPIO_Port GPIOA
#define DIST_SENSOR_AIN1_Pin GPIO_PIN_1
#define DIST_SENSOR_AIN1_GPIO_Port GPIOA
#define DIST_SENSOR_AIN2_Pin GPIO_PIN_2
#define DIST_SENSOR_AIN2_GPIO_Port GPIOA
#define SW1_IS_Pin GPIO_PIN_3
#define SW1_IS_GPIO_Port GPIOA
#define SW2_IS_Pin GPIO_PIN_4
#define SW2_IS_GPIO_Port GPIOA
#define SW3_IS_Pin GPIO_PIN_5
#define SW3_IS_GPIO_Port GPIOA
#define SW4_IS_Pin GPIO_PIN_6
#define SW4_IS_GPIO_Port GPIOA
#define SW5_IS_Pin GPIO_PIN_7
#define SW5_IS_GPIO_Port GPIOA
#define SW6_IS_Pin GPIO_PIN_4
#define SW6_IS_GPIO_Port GPIOC
#define M_IS_RIGHT_Pin GPIO_PIN_5
#define M_IS_RIGHT_GPIO_Port GPIOC
#define M_IS_LEFT_Pin GPIO_PIN_0
#define M_IS_LEFT_GPIO_Port GPIOB
#define SW4_DEN_Pin GPIO_PIN_1
#define SW4_DEN_GPIO_Port GPIOB
#define SW4_IN_Pin GPIO_PIN_2
#define SW4_IN_GPIO_Port GPIOB
#define SW5_T_Pin GPIO_PIN_10
#define SW5_T_GPIO_Port GPIOB
#define SW5_DEN_Pin GPIO_PIN_11
#define SW5_DEN_GPIO_Port GPIOB
#define SW5_IN_Pin GPIO_PIN_12
#define SW5_IN_GPIO_Port GPIOB
#define SW6_T_Pin GPIO_PIN_13
#define SW6_T_GPIO_Port GPIOB
#define SW6_DEN_Pin GPIO_PIN_14
#define SW6_DEN_GPIO_Port GPIOB
#define SW6_IN_Pin GPIO_PIN_15
#define SW6_IN_GPIO_Port GPIOB
#define ENC1_A_Pin GPIO_PIN_6
#define ENC1_A_GPIO_Port GPIOC
#define ENC1_B_Pin GPIO_PIN_7
#define ENC1_B_GPIO_Port GPIOC
#define MOTOR_DIR_RIGHT_Pin GPIO_PIN_8
#define MOTOR_DIR_RIGHT_GPIO_Port GPIOC
#define MOTOR_DIR_LEFT_Pin GPIO_PIN_9
#define MOTOR_DIR_LEFT_GPIO_Port GPIOC
#define MOTOR_PWM_LEFT_Pin GPIO_PIN_10
#define MOTOR_PWM_LEFT_GPIO_Port GPIOA
#define MOTOR_PWM_RIGHT_Pin GPIO_PIN_11
#define MOTOR_PWM_RIGHT_GPIO_Port GPIOA
#define DIGITAL_IN6_Pin GPIO_PIN_15
#define DIGITAL_IN6_GPIO_Port GPIOA
#define DIGITAL_IN5_Pin GPIO_PIN_10
#define DIGITAL_IN5_GPIO_Port GPIOC
#define DIGITAL_IN4_Pin GPIO_PIN_11
#define DIGITAL_IN4_GPIO_Port GPIOC
#define DIGITAL_IN3_Pin GPIO_PIN_12
#define DIGITAL_IN3_GPIO_Port GPIOC
#define DIGITAL_IN2_Pin GPIO_PIN_2
#define DIGITAL_IN2_GPIO_Port GPIOD
#define DIGITAL_IN1_Pin GPIO_PIN_4
#define DIGITAL_IN1_GPIO_Port GPIOB
#define LED_Pin GPIO_PIN_5
#define LED_GPIO_Port GPIOB
#define ENC2_A_Pin GPIO_PIN_6
#define ENC2_A_GPIO_Port GPIOB
#define ENC2_B_Pin GPIO_PIN_7
#define ENC2_B_GPIO_Port GPIOB

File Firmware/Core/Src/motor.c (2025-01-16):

/*
 * motor.c
 *
 *  Created on: Jan 9, 2025
 *      Author: krzysztof.tomicki
 */

#include "motor.h"

/*	INSTRUCTIONS HOW TO USE THIS LIBRARY
 *	1. Set PWM for motor control
 * 	2. Use init function
 * 	3. You can now do everything :))
 */

//PID variables scaled by 1000 to send easier via CAN bus
static int32_t Kp = 0.8 * 1000;
static int32_t Ki = 0.5 * 1000;
static int32_t Kd = 0.1 * 1000;
static int32_t integral = 0;
static int32_t previous_error = 0;

void Motor_Init(void)
{
	//set all control pins to low
	HAL_GPIO_WritePin(MOTOR_DIR_RIGHT_GPIO_Port, MOTOR_DIR_RIGHT_Pin, GPIO_PIN_RESET);
	HAL_GPIO_WritePin(MOTOR_DIR_LEFT_GPIO_Port, MOTOR_DIR_LEFT_Pin, GPIO_PIN_RESET);

	HAL_TIM_PWM_Start(&htim1, MOTOR_PWM_RIGHT);
	HAL_TIM_PWM_Start(&htim1, MOTOR_PWM_LEFT);
	__HAL_TIM_SET_COMPARE(&htim1, MOTOR_PWM_RIGHT, 0);
	__HAL_TIM_SET_COMPARE(&htim1, MOTOR_PWM_LEFT, 0);
}

void Motor_Stop(void)
{
	HAL_GPIO_WritePin(MOTOR_DIR_RIGHT_GPIO_Port, MOTOR_DIR_RIGHT_Pin, GPIO_PIN_RESET);
	HAL_GPIO_WritePin(MOTOR_DIR_LEFT_GPIO_Port, MOTOR_DIR_LEFT_Pin, GPIO_PIN_RESET);

	__HAL_TIM_SET_COMPARE(&htim1, MOTOR_PWM_RIGHT, 0);
	__HAL_TIM_SET_COMPARE(&htim1, MOTOR_PWM_LEFT, 0);
}

void Motor_Percent_Control(const MotorDirection_t direction, int8_t velocity)
{
	//speed limits
	if (velocity > 100)
	{
		velocity = 100;
	}
	else if (velocity <= 0)
	{
		Motor_Stop();
		return;
	}

	//velocity percent into pulse conversion
	uint32_t pulse_value = (velocity * __HAL_TIM_GET_AUTORELOAD(&htim1))/100; //here pulse value will be set between 0 - 999

	//setting direction and PWM into STM pins
	if (direction == MOTOR_RIGHT)
	{
		//direction
		HAL_GPIO_WritePin(MOTOR_DIR_RIGHT_GPIO_Port, MOTOR_DIR_RIGHT_Pin, GPIO_PIN_SET);
		HAL_GPIO_WritePin(MOTOR_DIR_LEFT_GPIO_Port, MOTOR_DIR_LEFT_Pin, GPIO_PIN_RESET);

		//PWM
		__HAL_TIM_SET_COMPARE(&htim1, MOTOR_PWM_RIGHT, pulse_value);
		HAL_TIM_PWM_Start(&htim1, MOTOR_PWM_RIGHT);

		__HAL_TIM_SET_COMPARE(&htim1, MOTOR_PWM_LEFT, 0);
		HAL_TIM_PWM_Stop(&htim1, MOTOR_PWM_LEFT);
	}
	else if (direction == MOTOR_LEFT)
	{
		//direction
		HAL_GPIO_WritePin(MOTOR_DIR_RIGHT_GPIO_Port, MOTOR_DIR_RIGHT_Pin, GPIO_PIN_RESET);
		HAL_GPIO_WritePin(MOTOR_DIR_LEFT_GPIO_Port, MOTOR_DIR_LEFT_Pin, GPIO_PIN_SET);

		//PWM
		__HAL_TIM_SET_COMPARE(&htim1, MOTOR_PWM_RIGHT, pulse_value);
		HAL_TIM_PWM_Start(&htim1, MOTOR_PWM_LEFT);

		__HAL_TIM_SET_COMPARE(&htim1, MOTOR_PWM_LEFT, 0);
		HAL_TIM_PWM_Stop(&htim1, MOTOR_PWM_RIGHT);
	}
}

void Motor_PID_Control(MotorDirection_t direction, int32_t desired_RPM, int32_t current_RPM)
{
	// P
    int32_t error = (int32_t)(desired_RPM - current_RPM);
    int32_t P = Kp * error / 1000;

    // I
    integral += error;

    //anti-windup limit
    if (integral > 100000) integral = 100000;
    if (integral < -100000) integral = -100000;

    int32_t I = Ki * integral / 1000;

    // D
    int32_t derivative = error - previous_error;
    int32_t D = Kd * derivative / 1000;

    //SUM
    int32_t output = P + I + D;

    //limit output range from 0 - 100% duty
    if (output > 100000) { output = 100000;}
    if (output < 0) { output = 0;}

    // making pwm from output value
    uint8_t pwm_duty_cycle = (uint8_t)(output / 1000);

    //Motor control
    Motor_Percent_Control(direction, pwm_duty_cycle);

    //update last error for next iteration
    previous_error = error;
}

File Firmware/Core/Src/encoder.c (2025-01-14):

/*
 * encoder.c
 *
 *  Created on: Jan 10, 2025
 *      Author: krzysztof.tomicki
 */

#include "encoder.h"

#define IMPULSES_PER_ROTATION (462)
#define SECONDS_IN_MINUTE (60)
#define SCALE_FACTOR (1000)
#define PE_PER_IMPULSE (4)
#define FREQUENCY (10)

/*	INSTRUCTIONS HOW TO USE THIS LIBRARY
 *	1. Turn on Timers in encoder mode
 * 	2. Use init functions on timers
 * 	3. You need to set one internal timer to make overfloat interrupt with f=1Hz
 * 	4. Enable interrupts e.g. HAL_TIM_Base_Start_IT(&htim2);
 * 	5. Write function to handle interrupts void HAL_TIM_PeriodElapsedCallback(TIM_HandleTypeDef *htim);
 * 	6. Use Encoder_GetRPM function inside Callbackfunction to get RPM
 */

void Encoder_Init(Encoder_Type_t encoder)
{
	// choose one of 2 encoders built in controller
	switch (encoder)
	{
	case ENCODER_5V:
		HAL_TIM_Encoder_Start(&htim4, TIM_CHANNEL_ALL); //start encoder
		__HAL_TIM_SET_COUNTER(&htim4, 0); //reset counter to 0
		break;
	case ENCODER_12V:
		HAL_TIM_Encoder_Start(&htim8, TIM_CHANNEL_ALL);
		__HAL_TIM_SET_COUNTER(&htim8, 0);
		break;
	default:
		break;
	}
}

uint32_t Encoder_GetScaledRPM(Encoder_Type_t encoder)
{
	//choose encoder timer
    TIM_HandleTypeDef *htim;
    switch (encoder)
    {
        case ENCODER_5V:
            htim = &htim4;
            break;
        case ENCODER_12V:
            htim = &htim8;
            break;
        default:
            Error_Handler();
            return 0;
    }

    //calculations
    uint32_t impulses = htim->Instance->CNT;
    impulses /= PE_PER_IMPULSE;

    uint32_t RPM_scaled = (impulses * SCALE_FACTOR * SECONDS_IN_MINUTE * FREQUENCY) / IMPULSES_PER_ROTATION;

    __HAL_TIM_SET_COUNTER(htim, 0);
    return RPM_scaled;
}

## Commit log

2025-01-09 project: add distance sensor pins and resolve clock issues
    [main.c, main.h]
2025-01-09 project: add motor control files
2025-01-09 project: add motor init and motor percent control function
2025-01-09 project: add Motor_Stop function and solved problem with negative velocity input
    [motor.c]
2025-01-09 project: configure encoder pins
2025-01-09 project: add 2 new files led.c and led.h with basic functions
2025-01-09 project: add toggle and blink with interval functions to led files
2025-01-09 project: one macro added to led.c
2025-01-10 project: add 2 new files encoder.c and encoder.h with init function, small corrections with #include main.h
    [encoder.c, main.h, motor.c]
2025-01-13 project: make encoder enum names more clear for the user by adding voltage in names
2025-01-13 project: prototype of filter configuring function
2025-01-13 project: working CAN bus with working filtering
2025-01-13 project: small correct in comment
    [main.c]
2025-01-13 project: correction in calling encoder init functions
    [main.c]
2025-01-13 project: turn on timer to help calculacte RPM
2025-01-13 project: clearing files for better work with encoder
2025-01-13 project: test of sending informations via CAN once a second for encoder purposes
2025-01-14 project: correctly getting impulses from encoder once a second
    [encoder.c, main.c]
2025-01-14 project: calculating scaled RPM is working correctly
    [encoder.c, main.c]
2025-01-14 project: configuring Encoder RPM function to handle 5 and 12V encoders
2025-01-14 project: refactoring RPM encoder function to make the code more readible
2025-01-14 project: changing RPM freq to 10Hz
2025-01-16 project: add PID regulation in main.c function
2025-01-16 project: working PID control function in motor files
2025-01-16 project: small comment in motor.c
2025-01-16 project: setup of peripheral pins to control high current switches on second board and also pins to measure current from motor half bridges
2025-01-16 project: function to switch on/off diagnostic of power switches
2025-01-17 project: add basic CAN Id based commands and remove led_blink function
2025-01-17 project: motor control via CAN
2025-01-17 project: add motor percent control via CAN
2025-01-17 Add PID motor control graph
2025-01-20 project: bugfix with only turning on power switches - now it also turns off
    [can_logic.c, main.c]
2025-01-20 project: update readme for new power switches code
2025-01-20 one more switches update for readme
2025-01-20 project: correction in files
    [can.c, can_logic.c, encoder.c]
2025-01-30 project: add lower board in final state
2025-01-30 project: add upper board in final state
2025-01-30 project: add board in cover
2025-03-07 README: Add new 3D render of the main board
2025-03-09 Project: add Main PCB project
    [Sterownik-DC.kicad_pcb, Sterownik-DC.kicad_sch]
2025-03-16 Project: add Extension Board PCB files
    [Sterownik-DC.kicad_pcb, Sterownik-DC.kicad_sch]
2025-03-16 Project: add ICs 3D models to the extension board render image

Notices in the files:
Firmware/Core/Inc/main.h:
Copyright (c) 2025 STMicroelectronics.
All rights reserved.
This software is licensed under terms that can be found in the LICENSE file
